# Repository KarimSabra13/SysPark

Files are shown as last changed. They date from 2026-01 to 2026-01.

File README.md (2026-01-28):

# SysPark – Smart Parking System (Documentation Repository)

SysPark is a smart parking demonstrator built as a distributed embedded system.  
This repository is a **documentation-first** deliverable: it contains architecture, flows, integration procedures, and reference documents. Source code can be added later without changing the documentation structure.

## 1) What SysPark does

SysPark automates entry and exit flows using multiple identification and control layers:

- **Entry lane**
  - Identify a user or a vehicle (RFID and optionally license plate)
  - Trigger actuation (barrier and/or elevator mechanism in the demonstrator)
  - Create a parking session

- **Exit lane**
  - Identify the vehicle/session
  - Validate payment (cloud-driven)
  - Unlock the exit sequence
  - Close the session

SysPark is designed to remain safe and usable even when:
- the cloud is unavailable,
- vision is unavailable,
- network connectivity is degraded.

## 2) System blocks (high-level)

SysPark is split into independent blocks that communicate mainly through MQTT.

### Edge Gateway (BeagleY-AI / BeagleBone AI class)
- Local MQTT broker (system bus on the parking LAN)
- Bridge between local LAN and the cloud
- Orchestration logic (system flows, supervision)
- Remote maintenance entry point (VPN overlay recommended)
- Optional hosting of AI/Vision inference

### FPGA Execution Node (Nexys A7-100T + LiteX RISC-V + Linux)
- Deterministic actuator control via CSR (memory-mapped control registers)
- Receives commands from MQTT and publishes barrier states
- Runs Linux to host integration services while keeping a simple control plane
- Uses a structured boot chain (LiteX BIOS → OpenSBI → Linux kernel + DTB + initramfs)

### STM32 Field Nodes (STM32F746G-DISCO + Zephyr RTOS)
- Ethernet-connected nodes close to lane equipment
- Real-time threading model (RFID acquisition, UI updates, storage, motion control)
- microSD persistence for local autonomy (PINs, ACL whitelist, minimal logs)
- Entry vs Exit roles supported depending on the lane

### AI / Vision (optional)
- License plate recognition pipeline at the edge
- Confidence-aware publishing to MQTT
- Never blocks the lane: always has fallback identifiers

### Power and Hardware
- Battery pack + BMS for protection and balancing
- DC-DC conversion (12 V class rail to stable 5 V distribution)
- Wiring topology designed for demo robustness (noise isolation, labeling, safety)

## 3) Repository structure

This repo is organized as a documentation system.

- `README.md`  
  Global overview (this file)

- `README.fr.md`  
  French version of the global overview

- `docs/en/`  
  English documentation by subsystem

- `docs/fr/`  
  French documentation by subsystem (mirrors `docs/en/`)

- `references/pdf/`  
  Reference PDFs used for the project (presentation, BMS, datasheets)

- `assets/`  
  Images, diagrams, exports (architecture visuals, screenshots, figures)

- `CHANGELOG.md`  
  Documentation evolution history

- `LICENSE`  
  Repository license

### Documentation sections
Inside `docs/*/` you will find:
- `overview/` : architecture, requirements, system flows, security, testing, deployment
- `edge/` : gateway role, MQTT bridge, remote access, LED banner integration
- `fpga/` : RISC-V on FPGA, boot chain, CSR control, networking
- `stm32/` : node overview, RTOS threads, Ethernet, storage microSD
- `cloud/` : cloud overview, payments, MQTT topic taxonomy
- `ai-vision/` : pipeline, streaming, models, validation
- `hw/` : high-level BOM, power and BMS, wiring topology

## 6) Getting started (documentation navigation)

Start here:
- `docs/en/overview/architecture.md`
- `docs/en/overview/system-flows.md`
- `docs/en/overview/deployment.md`
- `docs/en/overview/testing.md`

Then read per subsystem:
- `docs/en/edge/beagley-ai.md`
- `docs/en/fpga/riscv-overview.md`
- `docs/en/stm32/stm32-overview.md`
- `docs/en/hw/power-bms.md`

French equivalents are mirrored under `docs/fr/`.

## 7) Reference documents

- Presentation: `references/pdf/SysPark_Présentation.pdf`
- Power and BMS reference: `references/pdf/BMS.pdf`

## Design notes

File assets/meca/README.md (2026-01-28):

# SysPark - Documentation Mécanique (Impression 3D)

Ce répertoire contient l'ensemble des fichiers de conception mécanique nécessaires à l'assemblage physique du système de parking **SysPark**.  
Toutes les pièces ont été conçues pour être fabriquées via **impression 3D (FDM)**.

## 📂 Contenu du dossier

Le projet est divisé en quatre sous-ensembles principaux.

### 1. Support principal (STM32 + RFID + LCD)

**Dossier**  
`Support stm+rfid+lcd`

**Description**  
Châssis central du nœud de contrôle. Il permet de fixer solidement la carte **STM32F746G-DISCO**, le lecteur de badges **RFID RC522** et l'écran LCD intégré.

**Usage**  
Unité d'interface utilisateur à l'entrée et à la sortie du parking.

### 2. Support Écran OLED (Ascenseur)

**Dossier**  
`Ecran OLED ascenseur`

**Description**  
Boîtier compact conçu pour accueillir l'écran OLED déporté **SSD1306**.

**Usage**  
Fixation sur la structure de l'ascenseur afin d'indiquer l'étage ou le statut du véhicule.

### 3. Supports Caméras

Le système utilise deux types de supports selon la technologie de vision employée.

**Caméra CSI**  
Support optimisé pour les caméras à nappe de type **Raspberry Pi** ou **BeagleY-AI**, idéal pour la reconnaissance de plaques en pose fixe.

**Caméra Logitech**  
Support universel adapté aux webcams USB **Logitech** (C170, C920) pour une surveillance grand angle.

## 🛠 Paramètres d'Impression Recommandés

Afin de garantir la solidité mécanique et la précision des emboîtements, notamment pour les connecteurs USB de la STM32, les paramètres suivants sont recommandés.

**Matériau**  
PLA ou PETG. Le PETG est conseillé si le système est exposé à la chaleur.

**Hauteur de couche**  
0.2 mm.

**Remplissage (Infill)**  
15 % à 20 %, motif Gyroid ou Grille.

**Supports**  
Généralement non requis pour le support STM32. Ils peuvent être nécessaires pour certains supports caméras selon l'orientation d'impression.

**Brim / Bordure**  
Recommandé pour les pièces larges afin d'éviter le warping et le décollement des coins.

## 🔧 Instructions d'Assemblage

**Préparation**  
Nettoyer les restes de supports et vérifier l'ébavurage des trous de fixation.

**Montage électronique**  
La carte STM32 se fixe sur ses plots à l'aide de vis M3 de 6 mm à 10 mm.  
Le lecteur RFID se glisse ou se visse dans son logement dédié en vérifiant l'alignement de l'antenne.

**Fixation caméra**  
Les supports caméras sont conçus pour être orientables. Les vis de pivot doivent être serrées une fois l'angle de vue optimal obtenu.

**Intégration OLED**  
L'écran OLED doit être inséré délicatement afin d'éviter toute casse de la dalle en verre. Une fixation par clips ou un point de colle chaude est prévue selon la version du fichier.

## 📝 Format des fichiers

**STL**  
Fichiers directement importables dans les slicers tels que Cura, PrusaSlicer ou Bambu Studio.

**Note**  
Les fichiers sources CAD peuvent être ajoutés sur demande pour permettre la modification des tolérances ou des dimensions.

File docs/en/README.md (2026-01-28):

# SysPark Docs (EN)

## Overview
- Architecture: ../en/overview/architecture.md
- System flows: ../en/overview/system-flows.md
- Requirements: ../en/overview/requirements.md
- Security: ../en/overview/security.md
- Deployment: ../en/overview/deployment.md
- Testing: ../en/overview/testing.md

## Subsystems
- Cloud: ../en/cloud/cloud-overview.md
- Edge (BeagleY-AI): ../en/edge/beagley-ai.md
- STM32 (Zephyr): ../en/stm32/stm32-overview.md
- FPGA (RISC-V on LiteX): ../en/fpga/riscv-overview.md
- AI/Vision: ../en/ai-vision/pipeline.md
- HW/Power: ../en/hw/power-bms.md

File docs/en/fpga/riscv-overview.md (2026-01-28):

Language: English | [Français](../../fr/fpga/riscv-overview.md)

# RISC-V on FPGA Overview (LiteX + Soft SoC)

SysPark uses a RISC-V system running on an FPGA to implement a deterministic “execution node” that can safely drive actuators (barriers, motors) while still supporting a Linux environment for integration, tooling, and network services.

The idea is to combine:
- **hardware determinism** for control and I/O,
- **software flexibility** for messaging, logging, and system integration.

---

## 1) Why run RISC-V on an FPGA in SysPark

### Deterministic and low-level I/O
Actuation (barrier open/close, motor sequences) benefits from:
- predictable timing,
- direct memory-mapped register access,
- the ability to implement safety timeouts close to the hardware.

### Fast iteration for custom hardware interfaces
On an FPGA, SysPark can add or modify:
- PWM/stepper controllers,
- CSR-mapped GPIO blocks,
- additional sensors/encoders,
- watchdog and safety state machines,
without relying on a fixed off-the-shelf controller.

### Linux integration without losing control
Running Linux on the soft SoC enables:
- MQTT client services,
- secure payload handling,
- remote logging and maintenance,
- fast prototyping of on-device logic.

The FPGA remains the place where the “last mile” execution is controlled and made safe.

---

## 2) LiteX in one sentence

LiteX is used to generate a customizable SoC on the FPGA:
- a RISC-V CPU core,
- bus interconnect,
- memory controllers,
- and **CSR registers** that expose custom hardware blocks to software.

In SysPark, LiteX is the bridge between custom control logic in HDL and software services running on the CPU.

---

## 3) Soft SoC building blocks (SysPark view)

A typical SysPark FPGA SoC contains:

### CPU subsystem
- RISC-V soft core (e.g., VexRiscv class)
- on-chip ROM/BIOS stage (LiteX BIOS)
- DRAM controller (when using external DDR)

### Peripheral subsystem
- CSR-mapped GPIO blocks (for PMOD inputs/outputs)
- custom control IP (stepper driver output sequencing, PWM, etc.)
- UART for console
- Ethernet or MAC support if used for networking
- timers and interrupts used by Linux and by low-level services

### Memory and storage
- boot medium (SD or SPI flash depending on setup)
- runtime memory (DDR)

---

## 4) What CSR means in SysPark

CSR stands for Control and Status Registers:
- memory-mapped registers created by LiteX,
- accessible by software through simple reads/writes,
- used to control custom hardware blocks (set outputs, read inputs, trigger actions).

In SysPark, CSR registers provide the “actuator interface”:
- barrier control outputs are written through CSR-mapped GPIO,
- sensor inputs are read through CSR-mapped GPIO,
- Linux services translate MQTT commands into CSR writes.

This architecture avoids complex driver stacks and keeps the control path simple and transparent.

---

## 5) Separation of concerns (why this architecture is clean)

SysPark intentionally separates:
- **Decision layer** (cloud policies, edge orchestration)
- **Execution layer** (FPGA + CSR control)
- **Field interaction layer** (STM32 nodes close to sensors/motors)

The FPGA node is focused on:
- deterministic execution,
- safety boundaries,
- reliable low-level I/O,
not on high-level business logic.

---

## 6) Typical responsibilities of the FPGA execution node

- Subscribe to the local MQTT bus (or receive commands via the edge gateway).
- Validate and translate commands into hardware actions.
- Drive barrier outputs (stepper or motor driver chain).
- Read sensor inputs and publish states.
- Enforce timeouts and safe states in case of faults or missing heartbeats.
- Provide a clear software interface to the rest of the system.

---

## 7) Why open RISC-V is a good match (project philosophy)

RISC-V fits SysPark’s approach because:
- open ISA, easy to explain and document,
- strong ecosystem for soft cores and FPGA SoCs,
- aligns with an engineering demo where transparency matters,
- simplifies educational and research-driven iteration.

In practice, the value is the ability to generate the exact SoC needed and expose precise hardware control surfaces.

---

## 8) Acceptance criteria for the FPGA node

A correct FPGA execution node integration provides:
- stable boot chain to Linux,
- predictable CSR access (no address mismatch),
- reliable actuator control under MQTT command load,
- correct sensor sampling and state publishing,
- safe recovery on faults and timeouts.

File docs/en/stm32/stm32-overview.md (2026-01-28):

Language: English | [Français](../../fr/stm32/stm32-overview.md)

# STM32 Subsystem Overview (STM32F746G-DISCO + Zephyr RTOS)

In SysPark, the STM32 subsystem is the **field node** deployed close to the physical lane equipment. It executes deterministic, safety-oriented tasks (motor control, limit switches, RFID, local UI) and synchronizes its state with the Edge gateway (BeagleY-AI) through **Ethernet + MQTT**.

SysPark separates responsibilities on purpose:
- **Edge gateway decides** (orchestrates flows, merges vision + policies, bridges cloud),
- **STM32 executes locally** (timing-sensitive control, reliable I/O handling, local UI),
- **Execution hardware remains safe by design** (watchdogs/timeouts handled where needed).

---

## 1) Role inside SysPark

### Real-time field control
The STM32 node runs the “close-to-hardware” logic:
- stepper motor control through a driver that supports STEP/DIR (and optional configuration interface),
- homing and motion safety using end-stop/limit switch feedback,
- RFID badge reading for local identification,
- local display updates for lane feedback,
- local persistence for critical parameters (PINs, whitelist).

### Network synchronization
The STM32 node publishes events and receives approved commands via MQTT over Ethernet:
- publishes identification and sensor/actuator states,
- subscribes to selected commands and authorizations (notably payment success in exit flow),
- remains usable even when cloud connectivity is degraded (LAN-first behavior).

---

## 2) Why Zephyr RTOS

Zephyr is used for three main reasons:

### Determinism
Field interactions need predictable latency:
- step timing and motor sequencing,
- limit switch handling,
- UI refresh without blocking critical tasks.

### Embedded networking maturity
Zephyr provides a structured networking stack (Ethernet + IPv4 + sockets + MQTT patterns) suitable for microcontrollers with explicit RAM/CPU trade-offs.

### Reproducibility
Zephyr encourages reproducible configuration and portability:
- consistent build/config model,
- hardware description decoupled from application logic,
- easy to align behavior between developer machines and integration setups.

---

## 3) Hardware platform choice: STM32F746G-DISCO

The STM32F746G-DISCO board was selected because it offers:
- a high-performance Cortex-M7 suitable for mixed I/O + networking workloads,
- an integrated ST-LINK for simple flashing/debug,
- convenient expansion headers for motor drivers, RFID readers, displays, and sensors,
- Ethernet connectivity supported by Zephyr (RMII PHY commonly used in this platform).

---

## 4) Interfaces and peripherals (SysPark configuration)

SysPark’s STM32 integration targets a clear set of peripherals:

### Motor and safety I/O
- Stepper motor driver interface (STEP/DIR) and configuration channel if needed
- Limit switch input used for homing and safety boundaries
- Clear “safe state” behavior when faults occur or commands are inconsistent

### Identification (RFID)
- RFID reader used to capture badge UID
- UIDs are normalized and forwarded to the system bus for authorization decisions

### Local user interfaces
- A character LCD (20×4) can present operational data (status, messages, contextual info)
- An OLED screen can be used to show elevator/motion status (floor, direction, homing progress)

### Storage (microSD)
A microSD card is used to persist key data across reboots:
- entry PIN and exit PIN (if those modes are enabled),
- whitelist of authorized badge UIDs,
- optional field logs (events and diagnostics) in a structured, low-write-rate pattern.

---

## 5) Networking model (Ethernet, static IP, and MQTT)

### Ethernet basics
- The STM32 is a LAN node and communicates directly with the Edge gateway.
- Static IPv4 addressing is used to keep integration simple and predictable during demos and testing.

### MQTT integration intent
The STM32 acts as an MQTT client:
- publishes local events (RFID, barrier/elevator state, limit switch state),
- consumes selected decisions coming from the orchestration layer.

A strict topic taxonomy must be shared with BeagleY-AI to prevent mismatches and to keep the bridge allowlist minimal.

---

## 6) Execution modes: entry vs exit roles

SysPark can assign the STM32 node a **lane role**:

### Entry role (with elevator/motion control)
- performs homing on startup,
- drives the elevator/motion sequence deterministically,
- publishes elevator state periodically for supervision and UI.

### Exit role (payment-gated exit)
- focuses on identification + UI + exit authorization,
- waits for a “payment validated” authorization event before allowing exit progression,
- keeps local safety rules independent from cloud availability.

---

## 7) Concurrency model (threads and synchronization)

The application is structured as cooperative modules running at different priorities:
- MQTT communications and routing
- RFID acquisition
- UI rendering (LCD and OLED)
- motion control (entry role only)
- payment UI routing (exit role)

Synchronization is implemented using:
- message queues for UID and payment events,
- a semaphore-like mechanism to unblock UI after payment confirmation,
- a lock to protect microSD access between concurrent activities.

The goal is to avoid blocking operations in time-critical paths and to keep networking/UI/logging isolated from motor timing.

---

## 8) Field logging and robustness principles

To remain reliable in a real site:
- logs are written in a controlled manner (buffered + periodic flush),
- critical buffers and file structures are kept stable in memory,
- stack sizing is treated as a first-class constraint (avoid runtime faults),
- network behavior is validated with isolated subnets to avoid lab/router conflicts.

A separate Ethernet test flow exists in SysPark work to validate:
- TCP reception behavior,
- UART display output,
- and safe storage to microSD (file rotation, periodic synchronization).

---

## 9) Optional audio exploration (project extension)

An audio module was explored to support voice prompts around the elevator system:
- first approach: external text-to-speech board controlled by the STM32,
- second approach: investigation of the on-board audio chain (SAI/I2S codec).

This module is considered optional and was primarily used to evaluate feasibility and integration cost under Zephyr constraints.

---

## 10) Integration expectations (what “good” looks like)

A correct STM32 subsystem integration should provide:
- predictable motion control and safe homing,
- reliable RFID UID reporting,
- consistent UI behavior aligned with lane states,
- stable Ethernet connectivity and MQTT publication/subscription,
- robust behavior in degraded modes (cloud unreachable, broker unreachable),
- traceable local persistence (PINs/whitelist) and minimal SD wear.

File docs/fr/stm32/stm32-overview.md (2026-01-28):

Language: Français | [English](../../en/stm32/stm32-overview.md)

# Vue d’ensemble du sous-système STM32 (STM32F746G-DISCO + Zephyr RTOS)

Dans SysPark, le sous-système STM32 est le **nœud terrain** au plus près des équipements physiques de voie. Il exécute les tâches déterministes et orientées sûreté (pilotage moteur, fins de course, RFID, interface locale) et synchronise son état avec la passerelle Edge (BeagleY-AI) via **Ethernet + MQTT**.

SysPark sépare volontairement les responsabilités :
- **la passerelle décide** (orchestration, vision, politiques, bridge cloud),
- **le STM32 exécute localement** (contrôle I/O, temps réel, UI),
- **les mécanismes sûreté restent locaux** (comportement fiable en défaut).

---

## 1) Rôle dans l’architecture SysPark

### Contrôle terrain temps réel
Le STM32 gère la logique “proche matériel” :
- pilotage d’un moteur pas-à-pas via une interface driver de type STEP/DIR (et configuration si besoin),
- homing et limites mécaniques via fin de course,
- lecture badge RFID pour identification locale,
- mise à jour d’un affichage local,
- persistance locale des paramètres critiques (PIN, whitelist).

### Synchronisation réseau
Le STM32 publie des événements et reçoit des commandes approuvées via MQTT sur Ethernet :
- publication UID RFID et états capteurs/actionneurs,
- réception de certaines décisions (dont la validation de paiement en mode sortie),
- fonctionnement local prioritaire même en mode cloud dégradé.

---

## 2) Pourquoi Zephyr RTOS

Trois raisons principales :

### Déterminisme
Les interactions terrain demandent une latence maîtrisée :
- cadence moteur et séquences,
- lecture fin de course,
- rafraîchissement UI sans bloquer le critique.

### Réseau embarqué mature
Zephyr propose une pile réseau structurée (Ethernet + IPv4 + patterns MQTT) adaptée à microcontrôleur avec compromis explicites RAM/CPU.

### Reproductibilité
Modèle de configuration et d’intégration cohérent :
- configuration homogène,
- description matériel découplée,
- intégration reproductible en dev et en démo.

---

## 3) Plateforme matérielle : STM32F746G-DISCO

Choisie car :
- Cortex-M7 performant pour combiner I/O + réseau,
- ST-LINK intégré (flash/debug),
- headers pratiques pour driver moteur, RFID, écrans, capteurs,
- Ethernet compatible avec Zephyr (PHY RMII couramment utilisé sur cette carte).

---

## 4) Interfaces et périphériques (configuration SysPark)

SysPark cible un ensemble clair de périphériques :

### Moteur et sûreté I/O
- interface driver moteur (STEP/DIR) + canal de configuration si nécessaire
- fin de course pour homing et limites sûreté
- comportement en état sûr en cas d’anomalie ou de commande incohérente

### Identification (RFID)
- lecteur RFID pour récupérer l’UID badge
- normalisation de l’UID et publication sur le bus système pour décision d’accès

### Interfaces locales
- LCD 20×4 pour messages opérationnels (statut, informations contextualisées)
- OLED pour suivi ascenseur/mouvement (étage, direction, homing)

### Stockage (microSD)
La microSD sert à persister des éléments clés :
- PIN entrée et PIN sortie (si ces modes sont activés),
- liste whitelist des badges autorisés,
- logs terrain optionnels, structurés, à faible fréquence d’écriture.

---

## 5) Modèle réseau (Ethernet, IP statique, MQTT)

### Ethernet
- Le STM32 est un nœud LAN et dialogue avec la passerelle.
- L’adressage IPv4 statique simplifie les intégrations et les démos.

### Intentions MQTT
Le STM32 agit comme client MQTT :
- publie les événements locaux (RFID, états barrière/ascenseur, fin de course),
- consomme certaines décisions issues de l’orchestration.

Une taxonomie de topics strictement partagée avec BeagleY-AI est nécessaire pour éviter les désalignements et garder l’allowlist du bridge minimale.

---

## 6) Modes d’exécution : rôle entrée vs rôle sortie

SysPark peut assigner un **rôle de voie** au STM32 :

### Rôle entrée (avec ascenseur/mouvement)
- homing au démarrage,
- séquences de mouvement déterministes,
- publication régulière de l’état ascenseur pour supervision et UI.

### Rôle sortie (sortie conditionnée au paiement)
- priorité à l’identification + UI + autorisation sortie,
- attente d’un événement “paiement validé” avant de progresser,
- sûreté locale indépendante de la disponibilité cloud.

---

## 7) Modèle de concurrence (threads et synchronisation)

L’application est organisée en modules à priorités distinctes :
- communication et routage MQTT
- acquisition RFID
- rendu UI (LCD et OLED)
- pilotage mouvement (uniquement rôle entrée)
- routage UI paiement (rôle sortie)

Synchronisation via :
- files de messages pour UID et événements paiement,
- mécanisme type sémaphore pour débloquer l’UI après confirmation paiement,
- verrou pour protéger l’accès microSD en concurrence.

Objectif :
- éviter le blocage dans les chemins critiques,
- isoler réseau/UI/logging du timing moteur.

---

## 8) Logs terrain et principes de robustesse

Pour rester fiable :
- écriture logs contrôlée (buffer + flush périodique),
- structures mémoire stables pour éviter comportements indésirables,
- dimensionnement des piles traité comme contrainte centrale,
- validation réseau sur sous-réseaux isolés pour éviter conflits routeur/lab.

Un flow Ethernet de test a été utilisé pour valider :
- réception réseau,
- affichage UART,
- stockage microSD robuste (rotation, sync périodique).

---

## 9) Extension audio (optionnelle)

Une piste audio a été explorée pour des prompts autour de l’ascenseur :
- solution externe text-to-speech pilotée par le STM32,
- étude de la chaîne audio intégrée (SAI/I2S codec).

Cette brique est optionnelle et a surtout servi à évaluer la faisabilité et le coût d’intégration sous Zephyr.

---

## 10) Attendus d’intégration (critères de bon fonctionnement)

Une intégration STM32 correcte doit fournir :
- homing et contrôle mouvement prévisibles et sûrs,
- reporting UID RFID fiable,
- UI cohérente avec les états de voie,
- connectivité Ethernet stable et échanges MQTT corrects,
- comportement robuste en modes dégradés (cloud/broker indisponibles),
- persistance traçable (PIN/whitelist) et usure SD minimisée.

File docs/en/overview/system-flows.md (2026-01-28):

Language: English | [Français](../../fr/overview/system-flows.md)

# SysPark System Flows

This document describes the end-to-end operational flows of SysPark, from power-up to normal entry/exit cycles, including vision-assisted decisions, payment, operator overrides, degraded modes, and emergency handling. The goal is to make every subsystem role explicit and to keep boundaries stable: **Edge decides**, **FPGA executes safely**, **STM32 handles local terrain interactions**.

---

## 0) System bring-up and readiness (power-on to operational state)

### Trigger
- Mains power applied or system starts from backup battery.

### Steps
1. **Power and safety checks**
   - 12 V bus stabilizes, DC/DC converters supply logic rails.
   - BMS validates safe conditions (cell voltages, current limits, temperature).
   - If BMS detects an unsafe condition, the system stays in a restricted state (no actuation).

2. **Network initialization**
   - Edge gateway, FPGA node, and STM32 node bring up Ethernet links.
   - Static or DHCP addressing is applied depending on site configuration.

3. **Local control-plane availability**
   - The **local MQTT broker** becomes available on the parking LAN.
   - The system transitions to “local-operational” mode even if internet is not yet available.

4. **Cloud connectivity (optional but preferred)**
   - The MQTT bridge starts forwarding a *whitelisted* subset of topics to the public broker.
   - The cloud server connects to the broker and re-enables remote supervision features (dashboard, payments, remote logs).

5. **Subsystem health reporting**
   - Each subsystem publishes a heartbeat/status (edge, FPGA, STM32, sensors).
   - Edge consolidates system readiness and sets the initial user-facing messages (display banner).

### Outputs
- System state transitions to **READY** when:
  - BMS is OK,
  - LAN communication is OK,
  - execution nodes report healthy state.

---

## 1) Entry flow (vehicle arrival → authentication → barrier open → logging)

### Trigger
- Vehicle presence detected at entry lane (loop sensor, IR sensor, or equivalent).

### Inputs
- Presence sensor event
- Optional: camera snapshot / LPR result
- Authentication: RFID badge and/or PIN (site-dependent)

### Steps
1. **Arrival detection**
   - Presence event is published.
   - Edge updates the local display: “Please identify” or “Welcome”.

2. **Authentication**
   - **RFID badge path** (typical):
     - STM32 reads the badge UID and publishes an identification event.
     - Edge evaluates access based on:
       - local cached whitelist (offline-capable), and/or
       - cloud-managed policy (online mode).
   - **PIN path** (optional):
     - User enters PIN on the local interface.
     - STM32 forwards the entered PIN result as an event for validation.

3. **Decision**
   - Edge decides whether entry is granted:
     - policy checks (authorized user, time windows, capacity),
     - anti-passback logic if enabled (prevent “double entry” without exit),
     - optional coupling with vision confidence (if using LPR as an extra factor).

4. **Execution command**
   - Edge sends a barrier open request to the execution layer.
   - The FPGA (or the actuator controller designated as the executor) performs:
     - deterministic drive sequence,
     - safety checks (timeouts, motion bounds),
     - safe-state behavior if anomalies occur.

5. **Barrier open confirmation**
   - Executor reports: opened / opening / error.
   - Edge updates display: “Proceed” / “Wait” / “Error, call operator”.

6. **State update and traceability**
   - Entry event is logged (local and/or cloud):
     - timestamp, method (RFID/PIN/vision-assisted),
     - user identifier (masked where needed),
     - barrier status and any alarms.
   - Occupancy counters are updated.

### Outputs
- Barrier opens when authorized.
- Occupancy increments and session begins (in cloud DB if online).

---

## 2) Exit flow with payment (vehicle arrival → fee calculation → payment → barrier open)

### Trigger
- Vehicle presence detected at exit lane.

### Inputs
- Presence sensor event
- Optional: License Plate Recognition (LPR) result
- Payment status from the cloud (Stripe or equivalent)
- Exit PIN (optional fallback), operator override (fallback)

### Steps
1. **Arrival detection**
   - Presence event is published.
   - Display prompts: “Processing exit…” or “Please wait”.

2. **Vehicle identification**
   - Preferred: LPR provides plate number (+ confidence + timestamp).
   - Fallbacks:
     - RFID badge at exit,
     - exit PIN,
     - operator-assisted exit (manual override).

3. **Fee computation**
   - Cloud server computes fee based on session duration, tariffs, and rules.
   - Cloud emits a payment request event (amount, session reference).

4. **Payment interaction**
   - User completes payment through the cloud front-end.
   - Payment confirmation is generated by the payment provider and validated by the cloud (webhook).
   - Cloud publishes a **payment success** event linked to the session.

5. **Exit authorization**
   - The exit STM32 node receives “payment success” and unlocks the exit step.
   - Edge requests barrier opening from the executor.

6. **Execution + confirmation**
   - Executor opens the barrier with safety enforcement.
   - System logs:
     - payment confirmation,
     - exit timestamp,
     - barrier state and any warnings.

7. **Occupancy update**
   - Occupancy decrements.
   - Session is closed (in cloud DB if online).

### Outputs
- Barrier opens only after valid authorization (payment success or explicit override).
- Session is closed and revenue recorded.

---

## 3) Vision-assisted flow (camera → plate detection → OCR → validation → decision support)

### Trigger
- Vehicle presence or periodic capture policy.

### Inputs
- Camera frames (local capture)
- Vision model outputs (plate region, confidence)
- OCR result
- Validation rules (country format, allowed characters)

### Steps
1. **Capture and preprocessing**
   - Edge acquires frames and prepares them for inference.
   - Optional cropping or stabilization can be applied.

2. **Plate detection**
   - Vision model detects candidate plate region(s).
   - Edge selects the best candidate based on confidence and geometry.

3. **OCR and normalization**
   - OCR extracts characters.
   - Edge normalizes the string (cleanup, spacing, casing).
   - Format validation is applied (e.g., expected pattern constraints).

4. **Publishing results**
   - Edge publishes:
     - recognized plate,
     - confidence,
     - optional snapshot reference.

5. **Decision integration**
   - Entry: plate can be used as a second factor, or to pre-fill session identity.
   - Exit: plate is used to find the active session and compute fees.

### Failure handling
- If confidence is low or validation fails:
  - do not block the lane unnecessarily,
  - fallback to RFID/PIN/operator paths,
  - keep an “unverified plate” record for later review if needed.

---

## 4) Operator supervision and manual override flow (dashboard → action → audit)

### Trigger
- Operator opens the dashboard or receives an alert.

### Inputs
- System telemetry (status, heartbeats, alarms)
- Live debug stream (maintenance mode)
- Operator commands (manual barrier open, reset, config updates)

### Steps
1. **Observation**
   - Operator sees occupancy, recent events, alarm list, system health.
   - Optional: view a camera debug stream (secured access).

2. **Manual command**
   - Operator issues a command (e.g., open barrier, stop elevator, clear fault).
   - Command is authorized and logged (who/when/why).

3. **Execution**
   - Edge forwards the override request to the executor.
   - Executor performs action with safety limits.

4. **Audit trail**
   - Cloud stores the override event:
     - operator identity (or admin account),
     - reason (optional),
     - result and timing.

### Outputs
- Safe manual recovery path without bypassing the safety layer.

---

## 5) Configuration and access list management (cloud policy → edge → STM32 persistence)

### Trigger
- Admin updates authorized users, PINs, tariffs, or operational parameters.

### Inputs
- Admin action in the web interface
- Configuration payload (ACL list updates, PIN change, policy toggles)

### Steps
1. **Cloud publishes the update**
   - Changes are published as configuration events.

2. **Edge enforces boundaries**
   - Edge forwards only allowed configuration families to local systems.
   - Sensitive updates can require stronger authentication rules.

3. **STM32 applies and persists**
   - STM32 updates local stored configuration (e.g., whitelist, PINs) on SD storage.
   - STM32 republishes a “sync OK” status so the cloud knows it is applied.

### Outputs
- Offline-capable access control (cached whitelist / PINs).
- Clear “who changed what and when” traceability.

---

## 6) Degraded modes (internet down, broker down, subsystem fault)

SysPark is designed to keep the parking usable under partial failures.

### A) Internet down (cloud unreachable)
- Local broker continues functioning.
- Edge keeps basic entry/exit working with cached policies.
- Payments may be disabled or replaced by:
  - RFID-only exit for trusted users,
  - exit PIN,
  - operator override,
  depending on site policy.

### B) Cloud reachable but local execution node fault
- If an executor reports fault:
  - edge blocks automatic commands,
  - displays a clear user message,
  - notifies operator,
  - allows only manual recovery actions if safe.

### C) Vision degraded
- Vision failures should not block the lane:
  - revert to RFID/PIN,
  - store diagnostic markers for later tuning.

### D) Local broker down
- System can switch to a direct control-plane fallback if defined:
  - edge can attempt direct communication to executors,
  - or system can enter restricted state until broker returns.
- Recommended: keep broker as a supervised service with auto-restart.

---

## 7) Safety and emergency flow (obstruction, timeouts, fire alert)

### Trigger examples
- Obstruction detected while barrier closing.
- Movement timeout or inconsistent state.
- Fire alert signal received through an independent channel.

### Core safety rules
1. **Stop and safe state first**
   - executor stops motion and transitions to a safe state if:
     - obstruction is detected,
     - motion exceeds time window,
     - state becomes inconsistent.

2. **Clear operator messaging**
   - display: “Obstacle detected, please clear area” or “Call operator”.

3. **Alarm propagation**
   - alarm events are published locally and (if possible) forwarded to cloud.
   - operator is notified.

4. **Emergency policy**
   - for fire alert: apply the site-defined emergency policy, typically:
     - stop non-essential motion,
     - enable free exit or open barriers if safe and required,
     - keep logging for after-action review.

### Outputs
- Safety always overrides convenience.
- Emergency handling remains operational even if the main IP network is compromised.

---

## 8) What is logged (traceability baseline)

For each session and critical event, SysPark targets a consistent trace set:

- timestamps (entry, exit, payment success),
- authentication method (RFID, PIN, vision-assisted, override),
- system states and executor outcomes,
- alarms and recovery actions,
- operator actions with audit trail (when applicable).

This makes the system reviewable, debuggable, and demonstrable in an engineering context.

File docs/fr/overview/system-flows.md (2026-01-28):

Language: Français | [English](../../en/overview/system-flows.md)

# Flows système SysPark

Ce document décrit les flows opérationnels de SysPark, depuis la mise sous tension jusqu’aux cycles entrée/sortie, en incluant l’aide par vision, le paiement, les overrides opérateur, les modes dégradés et la gestion d’urgence. Objectif : rendre les rôles explicites et garder des frontières stables : **la passerelle décide**, **le FPGA exécute en sûreté**, **la STM32 gère les interactions terrain**.

---

## 0) Mise en route et état “READY” (power-on → système opérationnel)

### Déclencheur
- Alimentation secteur appliquée ou démarrage via la batterie de secours.

### Étapes
1. **Énergie et sûreté**
   - Stabilisation du bus 12 V, activation des conversions DC/DC.
   - Validation BMS (tensions cellules, limites courant, températures).
   - En cas d’anomalie BMS : système en état restreint (pas d’actionneurs).

2. **Initialisation réseau**
   - La passerelle, le FPGA et la STM32 montent les liens Ethernet.
   - Adressage statique ou DHCP selon configuration site.

3. **Plan de contrôle local**
   - Le **broker MQTT local** est disponible sur le LAN du parking.
   - Le système peut fonctionner en mode local même sans Internet.

4. **Connexion cloud (optionnelle mais recommandée)**
   - Le pont MQTT relaye une liste *whitelistée* de topics vers le broker public.
   - Le serveur cloud se connecte et réactive supervision et paiements.

5. **Santé sous-systèmes**
   - Chaque bloc publie un heartbeat/statut (passerelle, FPGA, STM32, capteurs).
   - La passerelle consolide l’état global et initialise les messages d’affichage.

### Sorties
- Passage en **READY** quand :
  - BMS OK,
  - communication LAN OK,
  - nœuds d’exécution en état sain.

---

## 1) Flow Entrée (arrivée véhicule → authentification → ouverture barrière → traçabilité)

### Déclencheur
- Présence véhicule détectée à l’entrée (capteur boucle/IR/etc.).

### Entrées
- Événement capteur de présence
- Optionnel : snapshot caméra / lecture plaque
- Authentification : badge RFID et/ou PIN (selon site)

### Étapes
1. **Détection arrivée**
   - Publication de l’événement de présence.
   - Mise à jour affichage : “Veuillez vous identifier” / “Bienvenue”.

2. **Authentification**
   - **Chemin badge RFID** (typique) :
     - STM32 lit l’UID et publie un événement d’identification.
     - La passerelle évalue l’accès via :
       - une whitelist locale mise en cache (mode offline), et/ou
       - une politique gérée côté cloud (mode online).
   - **Chemin PIN** (optionnel) :
     - Saisie PIN sur l’interface locale.
     - STM32 publie le résultat pour validation.

3. **Décision**
   - La passerelle autorise ou refuse l’entrée selon :
     - droits utilisateur, plages horaires, capacité,
     - anti-passback si activé (éviter une double entrée sans sortie),
     - optionnel : utilisation de la confiance vision comme facteur complémentaire.

4. **Commande d’exécution**
   - La passerelle envoie la demande d’ouverture vers la couche d’exécution.
   - Le FPGA (ou l’exécuteur dédié) applique :
     - séquence déterministe,
     - checks sûreté (timeouts, limites),
     - état sûr si anomalie.

5. **Confirmation**
   - Retour d’état : ouvert / en cours / erreur.
   - Affichage : “Passez” / “Patientez” / “Erreur, contactez l’opérateur”.

6. **Mise à jour et traçabilité**
   - Journalisation locale et/ou cloud :
     - timestamp, méthode (RFID/PIN/vision),
     - identifiant (masqué si besoin),
     - état barrière et alarmes.
   - Mise à jour occupation.

### Sorties
- Ouverture barrière si autorisé.
- Occupation + session d’entrée créée (cloud si online).

---

## 2) Flow Sortie avec paiement (arrivée → calcul tarif → paiement → ouverture)

### Déclencheur
- Présence véhicule détectée à la sortie.

### Entrées
- Événement présence
- Optionnel : résultat lecture plaque (LPR)
- Statut paiement depuis le cloud (Stripe ou équivalent)
- PIN sortie (fallback), override opérateur (fallback)

### Étapes
1. **Détection arrivée**
   - Publication de présence.
   - Affichage : “Sortie en cours…” / “Veuillez patienter”.

2. **Identification véhicule**
   - Prioritaire : LPR fournit plaque (+ confiance + timestamp).
   - Fallbacks :
     - badge RFID sortie,
     - PIN sortie,
     - assistance opérateur (override).

3. **Calcul tarif**
   - Serveur cloud calcule selon durée, tarifs, règles.
   - Cloud publie une demande de paiement (montant, référence session).

4. **Paiement**
   - Paiement via interface cloud.
   - Confirmation validée côté cloud (webhook).
   - Publication d’un événement **paiement validé** lié à la session.

5. **Autorisation sortie**
   - STM32 sortie reçoit “paiement validé” et déverrouille l’étape sortie.
   - Passerelle demande ouverture barrière à l’exécuteur.

6. **Exécution + confirmation**
   - Exécuteur ouvre avec sûreté.
   - Journalisation :
     - preuve paiement,
     - timestamp sortie,
     - état barrière + warnings.

7. **Mise à jour occupation**
   - Occupation décrémentée.
   - Session clôturée (cloud si online).

### Sorties
- Ouverture uniquement après autorisation (paiement validé ou override explicite).
- Revenu et session enregistrés.

---

## 3) Flow Vision (caméra → détection plaque → OCR → validation → support décision)

### Déclencheur
- Présence véhicule ou politique de capture périodique.

### Entrées
- Frames caméra
- Sorties modèle vision (zone plaque, confiance)
- OCR
- Règles de validation (format, caractères autorisés)

### Étapes
1. **Capture + prétraitement**
   - Acquisition image, préparation pour inference.
   - Optionnel : crop/stabilisation.

2. **Détection plaque**
   - Détection des régions candidates.
   - Sélection meilleure hypothèse (confiance + géométrie).

3. **OCR + normalisation**
   - Extraction caractères.
   - Nettoyage (espaces, casse, caractères parasites).
   - Validation format.

4. **Publication**
   - Publication plaque reconnue, confiance, optionnel snapshot.

5. **Intégration décision**
   - Entrée : second facteur ou pré-identification.
   - Sortie : rattachement à la session active pour calcul tarif.

### Gestion échecs
- Si confiance faible ou validation KO :
  - ne pas bloquer la voie,
  - basculer RFID/PIN/opérateur,
  - stocker un marqueur “non vérifié” pour analyse.

---

## 4) Supervision et override opérateur (dashboard → action → audit)

### Déclencheur
- Opérateur consulte le dashboard ou reçoit une alerte.

### Entrées
- Télémétries (statuts, heartbeats, alarmes)
- Flux debug (maintenance)
- Commandes opérateur (ouvrir barrière, reset, config)

### Étapes
1. **Observation**
   - Occupation, événements récents, alarmes, état système.
   - Optionnel : flux vidéo debug via accès sécurisé.

2. **Commande manuelle**
   - Action demandée (ouvrir barrière, stop mouvement, clear fault).
   - Autorisation + journalisation (qui/quand/pourquoi).

3. **Exécution**
   - Passerelle relaie vers l’exécuteur.
   - Exécuteur applique limites sûreté.

4. **Audit**
   - Cloud conserve l’événement :
     - identité opérateur/admin,
     - motif,
     - résultat et timing.

### Sorties
- Récupération sûre sans contourner la couche de sûreté.

---

## 5) Configuration et gestion des accès (politique cloud → passerelle → persistance STM32)

### Déclencheur
- Admin met à jour whitelist, PIN, tarifs, paramètres.

### Entrées
- Action admin via interface web
- Payload de configuration (ACL, PIN, options)

### Étapes
1. **Publication cloud**
   - Diffusion événement configuration.

2. **Contrôle passerelle**
   - Filtrage des familles autorisées vers le LAN.
   - Possibilité de renforcer l’auth sur changements sensibles.

3. **Application + persistance STM32**
   - STM32 met à jour config locale (whitelist/PIN) sur stockage SD.
   - STM32 publie “sync OK” vers le cloud.

### Sorties
- Mode offline possible (accès via cache).
- Traçabilité claire des changements.

---

## 6) Modes dégradés (perte Internet, panne nœud, vision KO)

SysPark vise une continuité d’usage sous pannes partielles.

### A) Internet indisponible
- Broker local continue.
- Passerelle maintient les flows basiques via cache.
- Paiements possibles à désactiver ou remplacer par :
  - sortie RFID pour utilisateurs de confiance,
  - PIN sortie,
  - override opérateur,
  selon politique site.

### B) Panne exécuteur local
- Si exécuteur en fault :
  - blocage automatique commandes,
  - affichage clair,
  - notification opérateur,
  - récupération manuelle encadrée si sûre.

### C) Vision dégradée
- Ne doit pas bloquer :
  - retour RFID/PIN,
  - collecte de diagnostics.

### D) Broker local indisponible
- Fallback possible si défini :
  - lien direct passerelle → exécuteurs,
  - ou état restreint jusqu’au retour broker.
- Recommandé : supervision service + auto-restart.

---

## 7) Flow sûreté et urgence (obstacle, timeout, alerte incendie)

### Déclencheurs typiques
- Obstacle pendant fermeture.
- Timeout mouvement ou état incohérent.
- Signal incendie via canal indépendant.

### Règles sûreté
1. **Stop + état sûr**
   - arrêt mouvement et état sûr si :
     - obstacle,
     - dépassement fenêtre temporelle,
     - incohérence d’état.

2. **Message utilisateur clair**
   - affichage : “Obstacle détecté, veuillez dégager” / “Contactez opérateur”.

3. **Propagation alarme**
   - publication locale puis cloud si possible.
   - notification opérateur.

4. **Politique urgence**
   - incendie : appliquer la politique définie site, typiquement :
     - arrêt mouvements non essentiels,
     - sortie libre ou ouverture barrière si requis et sûr,
     - journalisation pour post-mortem.

### Sorties
- La sûreté prime toujours.
- L’urgence reste gérable même si le réseau IP principal est compromis.

---

## 8) Ce qui est journalisé (base traçabilité)

Pour chaque session et événement critique :

- timestamps (entrée, sortie, paiement),
- méthode d’auth (RFID, PIN, vision, override),
- états système et résultats exécuteur,
- alarmes et actions de récupération,
- actions opérateur avec audit (si applicable).

Objectif : système démontrable, analysable, et maintenable.

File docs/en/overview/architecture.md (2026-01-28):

Language: English | [Français](../../fr/overview/architecture.md)

# SysPark System Architecture

SysPark is a modular smart-parking system designed as a complete, deployable solution rather than a loose set of sensors. The architecture is intentionally distributed and organized into clear responsibility layers, all interconnected over Ethernet. This separation keeps business decisions flexible while ensuring that safety-critical physical actions remain deterministic and robust.

## 1. Architectural principle: split responsibilities, keep interfaces stable

SysPark is built around three complementary execution layers:

- **Decision + supervision layer (Edge Gateway)**  
  A BeagleY-AI-class node is the integration point for high-level logic, cloud connectivity, vision/analytics, remote supervision, and operator-facing services.

- **Real-time execution layer (FPGA SoC)**  
  A Nexys A7 class FPGA running a LiteX SoC provides deterministic actuation and safety enforcement (timeouts, watchdogs, safe states). It executes commands reliably; it does not decide complex business rules.

- **Field interface layer (MCU node)**  
  An STM32F746G-DISCO class microcontroller running an RTOS handles local interactions near the equipment: RFID identification, elevator/actuator sequencing, local displays, and sensor acquisition, with predictable timing and structured multitasking.

A fourth cross-cutting block supports all layers:

- **Power + continuity layer (12 V bus + DC/DC + battery + BMS)**  
  A centralized 12 V DC bus simplifies distribution and supports heterogeneous loads. A backup battery and BMS provide continuity-of-service and energy safety, enabling controlled “safe shutdown” behavior.

This design rule stays constant across the project:

- **Beagle decides (business logic).**
- **FPGA executes (deterministic actuation + safety).**
- **STM32 interfaces with the field (local I/O + RTOS tasks).**

## 2. System-level topology

### 2.1 Networking and interconnection

All modules are connected using Ethernet, which standardizes integration and reduces point-to-point wiring complexity. A typical lab integration uses static IPv4 addressing for predictability (example values used during integration can be adapted per site):

- FPGA node: `192.168.10.4/24`
- Edge gateway: `192.168.10.5/24`
- STM32 node: `192.168.10.7/24`

Ethernet is used for:

- exchanging commands and acknowledgements,
- streaming sensor/actuator status to the gateway,
- transporting MQTT messages between subsystems (local broker and/or bridge).

### 2.2 Power distribution and continuity

SysPark uses:

- **12 V as the main distribution rail** (power domain),
- **5 V as the logic rail** (derived from 12 V via DC/DC conversion),
- a **backup battery** sized for peak power and safe-mode autonomy,
- a **BMS** ensuring protection, monitoring, and cell balancing.

The objective is not to replace mains permanently, but to **keep the system controllable long enough to finish a cycle, unlock safely, and enter a safe state** when supply conditions degrade.

## 3. Communication backbone: MQTT hybrid architecture

SysPark uses MQTT as the “system bus” for events, commands, telemetry, and operator messages.

### 3.1 Why hybrid (local + cloud)

The project uses a hybrid approach to get the best of both worlds:

- **Local MQTT broker** (inside the parking LAN):  
  fast local reactions, works even if internet is unstable, isolates sensitive equipment control.

- **Public broker relay + cloud server**:  
  enables remote supervision, centralized rule management, dashboards, payments and admin tools.

A **selective bridge** synchronizes only the required topics between local and cloud sides. A whitelist-based forwarding policy prevents loops and keeps the exposed surface minimal.

### 3.2 Topic taxonomy (conceptual)

Topics are structured hierarchically under a root (example: `parking/…`) to keep the system extensible. Typical families:

- `parking/sensor_*` for presence, gate sensors, health/heartbeat, errors
- `parking/gate/*` for barrier state, limit switches, commands
- `parking/display/*` for user-facing messages (LED banner, local UI)
- `parking/camera/*` for camera positioning commands and vision outputs
- `parking/config/*` for controlled configuration updates
- `parking/meteo` for contextual data (optional)

Quality-of-service is chosen per criticality:

- QoS 0 for non-critical periodic telemetry,
- QoS 1 for “must arrive at least once” commands,
- QoS 2 for critical configuration or safety events when exactly-once semantics matters.

## 4. Edge Gateway (BeagleY-AI): decision, fusion, supervision

The gateway is the system integration hub:

### 4.1 Decision engine and orchestration

It aggregates:

- field events (RFID, sensors, actuator status),
- vision outputs (plate recognition / confidence / snapshots),
- cloud-side decisions or policies (rules, capacity, operator overrides).

It then orchestrates:

- user guidance (display messages),
- barrier/elevator sequencing requests toward execution nodes,
- notifications and logging.

### 4.2 Local user information and remote supervision

Two key operator-facing functions are emphasized:

- **Local display**: a LED banner driven locally provides immediate feedback (“available spots”, “welcome”, “full”, “please wait”, etc.). The display subscribes to MQTT to update in real time.

- **Remote supervision**: a secure remote access tunnel enables operators/engineers to view a debug video stream without opening inbound ports on the site router. This supports maintenance and reduces deployment friction.

## 5. Field controller (STM32 + RTOS): deterministic terrain interactions

The STM32 subsystem is the “near-machine” node. It concentrates the physical I/O close to the barrier/equipment, and it uses RTOS multitasking to keep behavior predictable and maintainable.

### 5.1 Main responsibilities

- **RFID access control**: read badges and inject identification events into the system flow.
- **Actuator control (elevator, motors, etc.)**: execute local motion profiles with acceleration/deceleration logic, including a boot-time calibration (homing).
- **Local interface**: small displays and immediate user feedback.
- **Sensor acquisition**: temperature/pressure and other safety signals.
- **State synchronization**: publish status and receive commands over the network (via MQTT over Ethernet).

### 5.2 Design intent

The STM32 does not own complex business rules. It provides:

- stable and deterministic field I/O,
- clean separation of tasks (acquisition / display / communication),
- robust behavior under timing constraints.

## 6. FPGA SoC (Nexys A7 + LiteX + RISC-V Linux): deterministic execution and safety

The FPGA block exists to guarantee:

- **deterministic actuation timing**, independent of OS jitter,
- **safety enforcement** via watchdogs/timeouts and safe states,
- **reliable command execution** with explicit control interfaces.

### 6.1 Conceptual structure

- A LiteX SoC provides a clean separation between:
  - hardware logic for strict real-time functions,
  - a lightweight supervisory software layer running on a RISC-V CPU (Linux) for coordination and networking.

- Control is exposed through stable memory-mapped registers (CSR-like control surface), enabling explicit “set/read” semantics for actuators and status signals.

### 6.2 Integration flows

The FPGA exchanges with the gateway via Ethernet:

- **receives commands** to execute (open/close, position, drive),
- **returns status continuously** (states, positions, alarms),
- **enforces safe behavior** on anomaly detection.

## 7. Safety and emergency handling

Safety is designed into SysPark at multiple layers:

- **Local mechanical safety**: presence detection around barriers and controlled motion sequencing reduce risks.
- **Execution safety (FPGA)**: watchdogs/timeouts enforce safe states if commands become inconsistent or stale.
- **Energy safety (BMS)**: cell protection and safe operating area enforcement reduce thermal/chemical risk.
- **Emergency channel independence**: a fire alert mechanism is designed to use an independent radio channel outside the main IP network, ensuring the emergency signal can still reach the system in critical conditions.

## 8. Energy subsystem: BMS, battery sizing, and DC/DC strategy

The energy design is driven by heterogeneous loads and transient peaks:

- The overall system power budget is around the order of a few tens of watts, with peaks driven by motors/servos.
- A 12 V / 6 Ah battery is sized to sustain peak power and provide more than enough time to transition the system into a safe mode.
- The BMS functions include:
  - per-cell voltage monitoring, current and temperature tracking,
  - protection against over/under-voltage and over-current (MOSFET isolation),
  - passive balancing,
  - SOC/SOH estimation for supervision.

A pragmatic path was followed: initial custom BMS exploration for learning and architecture validation, then a commercial integrated BMS for reliability and delivery constraints.

## 9. Modularity and evolution

SysPark is designed to scale:

- from small sites (tens of spots) to larger deployments,
- to multiple entries/exits,
- to higher security requirements (more cameras, stronger policies),
- to additional sensing and diagnostics.

Because responsibilities are separated and interfaces are stable (Ethernet + MQTT + explicit status/command boundaries), new features can be added without destabilizing the safety-critical execution core.

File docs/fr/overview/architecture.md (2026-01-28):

Language: Français | [English](../../en/overview/architecture.md)

# Architecture système SysPark

SysPark est un système de parking intelligent conçu comme une solution complète, modulaire et orientée déploiement, plutôt que comme un simple assemblage de capteurs. L’architecture est volontairement distribuée, organisée en couches de responsabilités bien séparées, toutes interconnectées via Ethernet. Cette séparation permet de faire évoluer la logique métier sans fragiliser l’exécution temps réel et la sûreté des actions physiques.

## 1. Principe d’architecture : séparer les rôles, stabiliser les interfaces

SysPark repose sur trois niveaux complémentaires :

- **Niveau décision + supervision (Passerelle Edge)**  
  Un nœud de type BeagleY-AI sert de point d’intégration pour la logique haut niveau, la connectivité cloud, la vision, la supervision à distance et les services opérateur.

- **Niveau exécution temps réel (SoC sur FPGA)**  
  Un FPGA de type Nexys A7 avec un SoC LiteX assure l’exécution déterministe des commandes terrain et l’application des mécanismes de sûreté (timeouts, watchdogs, états sûrs). Il exécute de manière fiable, mais ne porte pas la décision métier complexe.

- **Niveau interface terrain (Nœud microcontrôleur)**  
  Un STM32F746G-DISCO sous RTOS gère les interactions locales au plus près des équipements : lecture RFID, séquencement ascenseur/actionneurs, affichage local, acquisition capteurs, avec une structure multi-tâches robuste.

Un bloc transverse supporte l’ensemble :

- **Énergie + continuité (Bus 12 V + conversion DC/DC + batterie + BMS)**  
  Un bus 12 V DC central simplifie la distribution, alimente les charges hétérogènes, et une batterie avec BMS garantit la continuité de service et la sûreté énergétique, afin d’atteindre un état sûr en cas de dégradation d’alimentation.

Règle d’architecture constante :

- **La passerelle décide (logique métier).**
- **Le FPGA exécute (temps réel + sûreté).**
- **La STM32 interfâce le terrain (I/O locales + tâches RTOS).**

## 2. Topologie système

### 2.1 Interconnexion réseau

Tous les modules communiquent via Ethernet, ce qui standardise l’intégration et limite le câblage point à point. En environnement de test, des adresses IPv4 statiques sont souvent utilisées pour la reproductibilité (valeurs indicatives, adaptables par site) :

- FPGA : `192.168.10.4/24`
- Passerelle : `192.168.10.5/24`
- STM32 : `192.168.10.7/24`

Ethernet sert à :

- transporter commandes, états et événements,
- échanger les statuts actionneurs/sécurités vers la passerelle,
- véhiculer les messages MQTT entre sous-systèmes (broker local et pont éventuel).

### 2.2 Distribution d’énergie et continuité

SysPark structure la puissance autour de :

- **12 V : rail principal** (puissance),
- **5 V : rail logique** (dérivé du 12 V par conversion DC/DC),
- une **batterie de secours** dimensionnée pour les pics et une autonomie de mise en sécurité,
- un **BMS** pour protection, mesure, équilibrage et supervision.

L’objectif n’est pas de remplacer durablement le secteur, mais de **maintenir le contrôle suffisamment longtemps pour terminer un cycle, sécuriser les actionneurs, puis basculer en état sûr**.

## 3. Colonne vertébrale de communication : MQTT hybride

MQTT est utilisé comme “bus système” pour les événements, commandes, télémétries et messages opérateur.

### 3.1 Intérêt du mode hybride (local + cloud)

L’architecture combine :

- **Un broker MQTT local** (sur le LAN du parking) :  
  latence faible, fonctionnement autonome même si l’accès Internet est instable, et contrôle mieux isolé.

- **Un relais public + un serveur cloud** :  
  supervision à distance, règles centralisées, tableaux de bord, paiements et administration.

Un **pont sélectif** synchronise uniquement les topics nécessaires entre local et cloud. Une politique de type whitelist évite les boucles et limite la surface exposée.

### 3.2 Taxonomie des topics (vue conceptuelle)

Les topics sont hiérarchiques sous une racine (ex : `parking/…`) pour rester extensibles. Familles usuelles :

- `parking/sensor_*` : présence, heartbeat, erreurs
- `parking/gate/*` : état barrière, fins de course, commandes
- `parking/display/*` : messages usagers (bandeau LED, IHM)
- `parking/camera/*` : commandes de positionnement et sorties vision
- `parking/config/*` : configuration contrôlée
- `parking/meteo` : contexte (optionnel)

Le QoS est choisi selon criticité :

- QoS 0 : télémetries non critiques,
- QoS 1 : commandes “au moins une fois”,
- QoS 2 : événements/configurations critiques si besoin d’exactement-une-fois.

## 4. Passerelle Edge (BeagleY-AI) : décision, fusion, supervision

La passerelle est le point d’intégration du système :

### 4.1 Moteur de décision et orchestration

Elle fusionne :

- événements terrain (RFID, capteurs, états actionneurs),
- sorties vision (lecture plaque, confiance, captures),
- règles et décisions issues du cloud (politiques, overrides opérateur).

Elle orchestre ensuite :

- guidage usager (messages d’affichage),
- demandes de séquences (barrières/ascenseur) vers les nœuds d’exécution,
- notifications et traçabilité.

### 4.2 Information locale et supervision à distance

Deux fonctions opérateur sont clés :

- **Affichage local** : un bandeau LED piloté localement fournit un retour immédiat (“places disponibles”, “bienvenue”, “complet”, etc.). Il est mis à jour en temps réel via abonnement MQTT.

- **Supervision à distance** : un accès distant sécurisé permet d’ouvrir un flux vidéo de debug sans ouvrir de ports entrants sur la box du site. Cela facilite maintenance, debug et déploiement.

## 5. Contrôleur terrain (STM32 + RTOS) : exécution locale et I/O déterministes

La STM32 est le nœud “au plus près” des équipements. Elle regroupe les entrées/sorties terrain et s’appuie sur une architecture RTOS multi-tâches pour garantir un comportement prévisible et maintenable.

### 5.1 Responsabilités principales

- **Contrôle d’accès RFID** : lecture badges et émission d’événements d’identification.
- **Commande actionneurs (ascenseur, moteurs, etc.)** : profils de mouvement avec accélération/décélération, et calibration (homing) au démarrage.
- **Interface locale** : affichages et retours utilisateur immédiats.
- **Acquisition capteurs** : température/pression et signaux de sûreté.
- **Synchronisation réseau** : publication d’états et réception de commandes via Ethernet/MQTT.

### 5.2 Intention de conception

La STM32 ne porte pas la logique métier complexe. Elle fournit :

- un socle terrain déterministe,
- un découpage clair des tâches (acquisition / affichage / communication),
- une robustesse temporelle adaptée aux contraintes réelles.

## 6. SoC FPGA (Nexys A7 + LiteX + RISC-V Linux) : déterminisme et sûreté d’exécution

Le FPGA garantit :

- **des temps d’exécution maîtrisés**, indépendants de la gigue OS,
- **des mécanismes de sûreté** (watchdogs, timeouts, états sûrs),
- **une exécution fiable** des commandes reçues.

### 6.1 Organisation conceptuelle

- Le SoC LiteX sépare :
  - la logique matérielle (fonctions strictement temps réel),
  - une couche de supervision légère (CPU RISC-V sous Linux) utile pour coordination et réseau.

- Le contrôle est exposé via une interface stable de type registres mémoire-mappés, offrant des commandes explicites et des retours d’état clairs.

### 6.2 Flux d’intégration

Le FPGA échange avec la passerelle via Ethernet :

- **réception de commandes** à exécuter,
- **retour continu d’état** (statuts, positions, alarmes),
- **passage en état sûr** lors de détection d’anomalies.

## 7. Sûreté et gestion d’urgence

La sûreté est traitée à plusieurs niveaux :

- **Sécurité locale** : capteurs de présence autour des barrières et séquences de mouvement contrôlées.
- **Sûreté d’exécution (FPGA)** : watchdogs/timeouts et états sûrs en cas d’incohérence.
- **Sûreté énergétique (BMS)** : protection cellules et respect de la zone de fonctionnement sûre.
- **Indépendance du canal d’urgence** : un mécanisme d’alerte incendie est pensé via un canal radio indépendant du réseau IP principal, afin de garantir la réception de l’alerte même en cas de panne réseau.

## 8. Énergie : BMS, dimensionnement batterie, conversion DC/DC

La conception énergie est dictée par des charges hétérogènes et des pics transitoires :

- un budget global de puissance de l’ordre de quelques dizaines de watts, avec des pics liés aux moteurs/servos,
- une batterie 12 V / 6 Ah dimensionnée pour tenir les pics et laisser le temps d’atteindre un état sûr,
- un BMS assurant :
  - mesure tension cellule, courant et température,
  - protection surcharge/sous-tension/surintensité (isolation par MOSFETs),
  - équilibrage passif,
  - estimation SOC/SOH exploitable en supervision.

La démarche a été pragmatique : exploration d’un BMS custom pour valider l’architecture, puis choix d’une solution commerciale intégrée pour sécuriser fiabilité et planning.

## 9. Modularité et évolutions

SysPark est conçu pour évoluer :

- du petit parking au multi-sites,
- en multipliant entrées/sorties,
- en renforçant sécurité et vision,
- en ajoutant capteurs, diagnostics et outils maintenance.

Grâce à la séparation des rôles et à des interfaces stables (Ethernet + MQTT + frontières commande/état), les nouvelles fonctionnalités peuvent être ajoutées sans déstabiliser le cœur d’exécution temps réel.

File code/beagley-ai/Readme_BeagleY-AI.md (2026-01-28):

# SysPark : Guide d'Implémentation du Nœud BeagleY-AI

## 1. Le Cœur Matériel : Analyse de la BeagleY-AI

Le choix de la plateforme matérielle est déterminant pour la viabilité d'une solution Edge AI. La **BeagleY-AI** a été sélectionnée pour SysPark en raison de son architecture hétérogène unique, offrant un équilibre optimal entre puissance de calcul généraliste et accélération matérielle spécialisée.

### 1.1 Spécifications Techniques et Pertinence pour SysPark

La BeagleY-AI repose sur le System-on-Chip (SoC) **Texas Instruments AM67A** (J722S), une puce conçue spécifiquement pour la vision industrielle et l'IA embarquée.<sup>12</sup>

| **Composant** | **Spécification** | **Rôle dans SysPark** |
|---|---|---|
| **CPU Application** | Quad-core Cortex-A53 @ 1.4 GHz (64-bit) | Exécution de l'OS Linux (Debian/TI Edge AI), du runtime Python, du broker MQTT et du serveur Web Flask. C'est le chef d'orchestre généraliste. |
| **Accélérateur IA (DSP)** | C7x DSP + MMA (Matrix Multiply Accelerator) | Capable de délivrer jusqu'à 4 TOPS (Trillions d'Opérations par Seconde). Il est dédié à l'inférence des réseaux de neurones profonds (YOLO) pour la détection de véhicules et de plaques, déchargeant le CPU principal. |
| **Processeur de Vision (ISP)** | VPAC (Vision Processing Accelerator) | Unité critique pour le pipeline vidéo. Elle traite le flux brut (RAW Bayer) des caméras, gère la balance des blancs, l'exposition automatique (AE) et la conversion de format (Demosaicing), sans latence CPU. |
| **Microcontrôleurs TR** | Cortex-R5F (x2) | Coeurs temps réel dédiés. Bien que SysPark utilise un STM32 externe, ces cœurs gèrent en interne la gestion de l'énergie et certains périphériques bas niveau du SoC. |
| **Mémoire** | 4 Go LPDDR4 | Suffisant pour stocker les modèles d'IA, les buffers vidéo GStreamer et l'OS complet. |
| **Connectivité** | Wi-Fi 6, Bluetooth 5.4, Gigabit Ethernet | Assure la liaison vers le Cloud (via Wi-Fi/Ethernet) et potentiellement vers des capteurs BLE futurs. |

Contrairement à une Raspberry Pi 4 ou 5 qui dépend fortement de son GPU VideoCore et de son CPU pour le traitement d'image, l'AM67A dispose de pipelines matériels dédiés (VPAC + DMPAC) qui permettent un traitement d'image déterministe et une consommation énergétique maîtrisée, crucial pour un boîtier de parking pouvant être exposé à la chaleur.

### 1.2 Topologie des Entrées/Sorties (Pinout) et Câblage

L'intégration physique de la BeagleY-AI dans le boîtier SysPark nécessite une compréhension précise du connecteur d'extension 40 broches. Bien que compatible physiquement avec le standard HAT Raspberry Pi, le multiplexage des broches (PinMux) sur le SoC TI AM67A est spécifique et nécessite une configuration logicielle précise via les "Device Tree Overlays".<sup>34</sup>

**Avertissement Critique** : Les niveaux logiques des GPIOs de la BeagleY-AI sont strictement en **3.3V**. Toute connexion directe avec des périphériques 5V (fréquents dans l'industrie ou sur Arduino/STM32 anciens modèles) sans adaptation de niveau (Level Shifter) entraînera la destruction immédiate du port GPIO, voire du SoC complet.<sup>5</sup>

#### 1.2.1 Le Bus SPI (Affichage LED Matriciel)

L'affichage des messages ("LIBRE", "COMPLET", Météo) est assuré par une chaîne de matrices LED pilotées par le contrôleur MAX7219. Ce composant utilise une interface série synchrone SPI (Serial Peripheral Interface). Sur la BeagleY-AI, nous exploitons le bus **SPI0** mappé pour correspondre au standard Raspberry Pi.<sup>6</sup>

-   **MOSI (Master Out Slave In) - Pin 19 (GPIO 10)** : C'est la ligne de données principale. La BeagleY-AI (Maître) envoie les commandes d'allumage des pixels aux modules LED (Esclaves). Le script bandeau_led.py écrit des trames binaires sur cette ligne.<sup>1</sup>

-   **SCLK (Serial Clock) - Pin 23 (GPIO 11)** : L'horloge de synchronisation. Générée par la BeagleY-AI, elle cadence la lecture des bits par le MAX7219. La fréquence est configurée à 1 MHz dans le script.

-   **CE0 (Chip Select 0) - Pin 24 (GPIO 8)** : Ligne de sélection de l'esclave. Lorsqu'elle est passée à l'état bas (Low), le MAX7219 écoute le bus. C'est essentiel pour initier une transaction SPI valide.

-   **MISO (Master In Slave Out) - Pin 21 (GPIO 9)** : Bien que présente physiquement, cette ligne n'est pas câblée aux matrices LED MAX7219 car la communication est unidirectionnelle (la BeagleY-AI envoie des données, mais les matrices ne répondent pas).

Pour que ces broches fonctionnent en mode SPI et non en GPIO simple, l'overlay k3-am67a-beagley-ai-spidev0.dtbo doit être chargé au démarrage.<sup>7</sup> Cela expose le périphérique /dev/spidev0.0 au niveau du noyau Linux.

#### 1.2.2 Interface GPIO (Capteur de Présence & Barrière)

La détection de véhicule à la barrière (simulation de boucle d'induction ou cellule photoélectrique) est gérée par une entrée numérique simple.

-   **Signal - Pin 11 (GPIO 17)** : Cette broche est configurée en entrée (Input). Le script sensor_gate.py <sup>1</sup> surveille l'état de cette ligne.

    -   *État Haut (3.3V)* : Véhicule présent (ou absence de faisceau, selon la logique du capteur - NC/NO).

    -   *État Bas (0V)* : Voie libre.

-   **Masse (GND) - Pin 9, 25, 39, etc.** : Référence commune obligatoire entre le capteur et la BeagleY-AI.

La documentation <sup>8</sup> confirme que la Pin 11 correspond bien au GPIO 17 du SoC (Net name : GPIO1_8 ou SoC Pin A26 selon le multiplexage, mais mappée logiciellement comme GPIO 17 pour compatibilité RPi).

#### 1.2.3 Interface Caméra (MIPI CSI-2)

La capture vidéo haute performance ne passe pas par l'USB (trop de latence et charge CPU), mais par l'interface **CSI (Camera Serial Interface)**.

-   **Connecteur** : La BeagleY-AI dispose de connecteurs 22-pin FPC (Flexible Printed Circuit).

-   **Modèle** : Caméra IMX219 (Sony Exmor R), standard de facto pour les projets embarqués.

-   **Topologie** : La caméra est connectée en point-à-point différentiel haut débit. Cela nécessite l'activation de l'overlay k3-am67a-beagley-ai-csi0-imx219.dtbo.<sup>2</sup> Cet overlay configure le PHY D-PHY du SoC pour recevoir les signaux LVDS de la caméra et router le flux vers le VPAC.

## 2. Stratégie Système : OS, Installation et Drivers

Le socle logiciel est le fondement de la stabilité de SysPark. Pour la BeagleY-AI, deux philosophies s'affrontent : l'image Debian générique maintenue par la fondation BeagleBoard, et l'image SDK (Software Development Kit) optimisée par Texas Instruments pour l'Edge AI.

### 2.1 Analyse Comparative des Images Système

Les recherches <sup>91011</sup> mettent en évidence une dichotomie critique :

1.  **Image BeagleBoard Debian (XFCE/Minimal)** :

    -   *Avantages* : Très proche d'une expérience Debian standard, mises à jour via apt, large support communautaire.

    -   *Inconvénients majeurs pour SysPark* : Le support de l'accélération matérielle (C7x DSP, VPAC ISP) et des plugins GStreamer associés (tiovxisp) est souvent expérimental, absent, ou nécessite une recompilation complexe du noyau et des modules.<sup>2</sup>

    -   *Risque* : Sans accélération, le traitement vidéo 1080p se ferait entièrement sur le CPU, saturant les cœurs A53 et rendant le système instable.

2.  **Image TI Edge AI (Basée sur Yocto/Arago)** :

    -   *Avantages* : Contient "out-of-the-box" tous les drivers propriétaires TI, les firmwares pour le DSP et le R5F, et surtout les plugins GStreamer tiovx optimisés. C'est l'image recommandée pour toute application de vision.<sup>12</sup>

    -   *Inconvénients* : Système de fichiers parfois en lecture seule (overlayFS), gestionnaire de paquets moins flexible (parfois opkg au lieu de apt, bien que les versions récentes intègrent apt), environnement plus "figé".

**Décision Architecturale** : Pour les déploiements SysPark, nous distribuons une **image disque SysPark prête à l'emploi** (basée sur TI Edge AI et déjà préconfigurée pour le projet). Cela garantit la disponibilité immédiate des drivers et accélérateurs (VPAC/tiovxisp, etc.) nécessaires au pipeline de vision, tout en figeant un socle stable pour l'intégration terrain.

### 2.2 Procédure d'installation et de mise en route (image SysPark prête à l'emploi)

Le nœud BeagleY-AI destiné à SysPark ne se déploie **pas** en réinstallant manuellement une distribution TI/Debian ni en reconstruisant l'environnement Python. Le système (serveur local, affichage LED, caméras, services, configuration de base) est livré sous forme **d'image disque** déjà préparée.

#### Phase 1 : Pré-requis

1. Une carte BeagleY-AI.
2. Une carte microSD de 16 Go minimum (32 Go recommandé).
3. Un ordinateur (Windows, macOS ou Linux) avec un lecteur microSD.
4. Un outil de flashage (balenaEtcher recommandé).

#### Phase 2 : Flashage de l'image SysPark sur microSD

1. Télécharger et installer balenaEtcher : [https://etcher.balena.io/](https://etcher.balena.io/)
2. Récupérer l'image disque SysPark (fichier `.img`) fournie pour le projet. [https://drive.google.com/file/d/1gn_GpR_V2WfZ9HwwYjGpSotGyj_53xE5/view?usp=sharing](https://drive.google.com/file/d/1gn_GpR_V2WfZ9HwwYjGpSotGyj_53xE5/view?usp=sharing)
3. Flasher la carte microSD avec balenaEtcher (sélection de l'image, sélection de la carte cible, écriture).
4. À la fin du flashage, certains systèmes (notamment Windows) peuvent proposer de formater la carte : il faut **refuser**. La carte contient des partitions Linux valides, simplement non reconnues par Windows.

#### Phase 3 : Premier démarrage

1. Éjecter proprement la microSD puis l'insérer dans la BeagleY-AI.
2. Brancher l'alimentation USB-C.
3. Connecter l'Ethernet (recommandé au premier démarrage).

Au premier boot, l'image peut effectuer une adaptation automatique à la taille de la microSD (extension de partition) et redémarrer. Laisser le nœud démarrer complètement (en pratique 1 à 2 minutes) afin que l'ensemble des services (serveur, affichage, vision, MQTT) se lance.

#### Phase 4 : Accès SSH (Ethernet préconfiguré)

Dans l'image SysPark, l'interface Ethernet est déjà configurée avec l'adresse statique suivante :

```bash
ssh root@192.160.10.1
```

Après connexion, sécuriser immédiatement le nœud (au minimum via la commande `passwd`). L'ajout d'un utilisateur non-root et l'authentification par clé SSH sont recommandés en exploitation, tout en gardant une procédure root disponible pour la maintenance.

#### Phase 5 : Accès au tableau de bord Web

Depuis un poste sur le même réseau, accéder au service Web local :

```text
http://192.160.10.1:5000
```

Selon l'environnement réseau (mDNS/Avahi), l'accès par nom peut aussi fonctionner :

```text
http://beagley-ai.local:5000
```

#### Phase 6 : Personnalisation obligatoire avant mise en service

L'image SysPark contient des réglages de démonstration et/ou de sauvegarde. Avant toute mise en service sur un nouveau site, il faut impérativement :

1. Changer la configuration Wi-Fi pour utiliser le réseau du site.
2. Remplacer toutes les clés / abonnements des services externes (HiveMQ Cloud, Tailscale, API météo, etc.) par les valeurs du client ou de l'exploitant.

Ces opérations sont détaillées en section 3.3.

#### Phase 7 : Comprendre le contenu de l’image SysPark (ce qui est déjà préinstallé)

L’image SysPark n’est pas seulement un système qui “démarre”, c’est un nœud BeagleY‑AI déjà câblé logiciellement pour exécuter la passerelle Edge du projet. Le dossier opérationnel est livré dans `/opt/edgeai-gst-apps` et les services correspondants sont déjà déclarés dans `/etc/systemd/system`.

##### 7.1 Matériel attendu et interfaces

Le fonctionnement nominal de l’image suppose la présence des éléments matériels suivants, car les scripts et services correspondants sont déjà prévus dans l’intégration.

Composant | Interface | Rôle
---|---|---
BeagleY‑AI | Carte SBC | Passerelle Edge, broker MQTT local, pont MQTT cloud, serveurs et logique locale
Caméra 1 IMX219 | CSI | Caméra principale pour la vision IA et la lecture de plaque
Caméra 2 USB | USB | Caméra secondaire, suivant l’intégration
Bandeau LED MAX7219 x4 | SPI (`/dev/spidev0.0`) | Affichage local des états et messages
Driver PCA9685 | I2C (`0x40`) | Génération PWM pour servos (Pan/Tilt)
Servomoteurs x4 | PWM | Orientation des deux caméras motorisées (Pan/Tilt)

##### 7.2 Arborescence livrée dans /opt/edgeai-gst-apps

Le projet est déployé directement dans `/opt/edgeai-gst-apps` et cette arborescence contient à la fois les scripts SysPark et des éléments “EdgeAI” issus de l’écosystème TI.

Référence de contenu observé dans l’image (extrait `ls`), utile pour se repérer lors d’un audit ou d’un dépannage.

```text
/opt/edgeai-gst-apps
Arducam-pivariety-v4l2-driver  (nom exact selon l’image)
CONTRIBUTING
LICENSE
README.md
[Unit]  (entrée anormale, peut être supprimée si inutile)
apps_cpp
apps_python
bandeau_led.py
beagle-ai.tail2fb2e4.ts.net.crt
beagle-ai.tail2fb2e4.ts.net.key
beagle_vision_combined.py
best.pt
cleaner.py
configs
docker
download_models.sh
download_test_data.sh
find_pins.py
force_all_neutra.sh
gate_zone_sensor.py
gnuradio
init_script.sh
optiflow
queue
scripts
sensor_gate.py
serveur
servo_calibration.py
servo_camera.py
setup_script.sh
simple_broker.py
start_vision.sh
test_simple_servo.py
tests
v4l2src
venv
```

Les éléments les plus importants, car directement liés au fonctionnement SysPark, sont les suivants.

Élément | Type | Rôle dans SysPark | Remarques d’exploitation
---|---|---|---
`beagle_vision_combined.py` | Script Python | Vision IA, détection, OCR, streaming MJPEG | Généralement lancé via `start_vision.sh`
`start_vision.sh` | Script shell | Point d’entrée vision | Active le venv et prépare `LD_LIBRARY_PATH` (plugins GStreamer)
`best.pt` | Modèle YOLO | Modèle de détection (plaques/véhicules) | À conserver avec le script vision
`simple_broker.py` | Script Python | Broker MQTT local (résilience) | Écoute typiquement en 1883
`mqtt_bridge.py` | Script Python | Pont MQTT local <-> cloud en TLS | Contient hôte, identifiants, CA, règles de filtrage
`bandeau_led.py` | Script Python | Pilotage bandeau LED (SPI) | Abonné à `parking/display/text`
`meteo_client.py` | Script Python | Client API météo et publication MQTT | Clé API et localisation à personnaliser
`sensor_gate.py` | Script Python | Lecture capteur présence barrière | Publie l’état sur MQTT
`servo_camera.py` | Script Python | Pilotage servos via PCA9685 (I2C) | Abonné à `parking/camera/cmd`
`venv/` | Dossier | Environnement Python isolé | Contient les dépendances déjà installées
`serveur/` | Dossier | Composants serveur local | Heberge le script mqtt_bridge.py et meteo_client.py
`beagle-ai.tail2fb2e4.ts.net.crt` et `.key` | Certificats | Artefacts liés à Tailscale | À régénérer après rattachement au compte Tailscale du client

L’arborescence contient aussi des outils et répertoires non spécifiques à SysPark, mais présents car l’image s’appuie sur l’écosystème TI EdgeAI, par exemple `apps_cpp`, `apps_python`, `optiflow`, `docker`, `tests`, ou des scripts utilitaires (`download_models.sh`, `download_test_data.sh`, etc.). Ils sont utiles pour diagnostiquer ou étendre, mais ne sont pas requis pour l’exploitation minimale.

##### 7.3 Services systemd déjà installés

Les scripts SysPark sont exécutés au démarrage via des unités systemd déjà présentes, notamment `simple_broker.service`, `mqtt_bridge.service`, `beagle_vision.service`, `bandeau_led.service`, ainsi que `meteo_client.service`, `sensor_gate.service` et `servo_camera.service`.

Référence de contenu observé dans l’image (extrait `ls`). Les unités `.service` ci-dessous portent le fonctionnement SysPark, le reste correspond au socle système et aux dépendances de démarrage.

```text
/etc/systemd/system
bandeau_led.service
beagle_vision.service
bluetooth.target.wants
ctrl-alt-del.target
dbus-org.bluez.service
dbus-org.freedesktop.Avahi.service
dbus-org.freedesktop.network1.service
dbus-org.freedesktop.resolve1.service
dbus-org.freedesktop.timesync1.service
dbus.service
default.target
display-manager.service
edgeai-init.service
getty.target.wants
local-fs.target.wants
meteo_client.service
mqtt_bridge.service
multi-user.target.wants
network-online.target.wants
sensor_gate.service
servo_camera.service
simple_broker.service
sockets.target.wants
sysinit.target.wants
systemd-hostnamed.service
systemd-journald.service.wants
systemd-random-seed.service.wants
systemd-udevd.service
timers.target.wants
```

Les sous-répertoires `*.target.wants` correspondent à des liens gérés par systemd pour l’activation automatique au boot.

Le point important est que les services sont le “contrat” d’exécution en production. Après modification d’identifiants (HiveMQ, Tailscale, météo) ou de paramètres matériels (caméra, SPI, I2C), il faut redémarrer le service concerné et vérifier ses logs via `journalctl`.

##### 7.4 Cartographie services <-> exécutables

Service systemd | Exécutable typique | Fonction
---|---|---
`simple_broker.service` | `simple_broker.py` | Broker MQTT local
`mqtt_bridge.service` | `mqtt_bridge.py` | Pont MQTT vers HiveMQ Cloud en TLS
`beagle_vision.service` | `start_vision.sh` puis `beagle_vision_combined.py` | Vision IA + streaming MJPEG
`bandeau_led.service` | `bandeau_led.py` | Bandeau LED SPI
`meteo_client.service` | `meteo_client.py` | Client météo, publication MQTT
`sensor_gate.service` | `sensor_gate.py` | Capteur présence, publication MQTT
`servo_camera.service` | `servo_camera.py` | Servos Pan/Tilt via I2C

##### 7.5 Accès au flux vidéo et maintenance à distance (Tailscale)

Le flux MJPEG issu du module vision est exposé classiquement sur le port 8000, avec une route de type `/mjpeg/cam1`. En local, cela permet de vérifier le cadrage et la mise au point sans outil spécifique.

```text
http://<IP_BEAGLE>:8000/mjpeg/cam1
```

Pour la télémaintenance, l’image peut s’appuyer sur Tailscale. Après rattachement au compte Tailscale du client, deux approches sont usuelles.

La première consiste à utiliser directement l’IP Tailscale (réseau 100.x) ou le nom MagicDNS de la machine pour atteindre le port 8000 à l’intérieur du réseau privé Tailscale.

La seconde consiste à activer un accès HTTPS public via Funnel sur ce port, ce qui renvoie une URL https unique.

```bash
sudo tailscale funnel 8000
```

Dans l’architecture SysPark, cette URL est ensuite reportée côté serveur cloud dans la variable historiquement nommée `NGROK_BASE` (même si le transport n’est pas ngrok) afin que les opérateurs puissent ouvrir le flux vidéo sans être sur le LAN du parking.

Après modification de l’accès distant, vérifier que les fichiers de certificat présents dans `/opt/edgeai-gst-apps` correspondent bien au domaine/compte Tailscale utilisé, puis régénérer si nécessaire.

### 2.3 Paramétrage initial après connexion (réseau, sécurité, abonnements)

Cette phase se fait directement en SSH (connexion root) après le premier démarrage.

#### 2.3.1 Sécurisation minimale

1. Changer le mot de passe root.

```bash
passwd
```

2. Configurer l'accès SSH par clés et, en production, limiter l'accès root (clé uniquement ou désactivation du login root), en s'appuyant sur un utilisateur d'exploitation dédié.

#### 2.3.2 Configuration Wi-Fi (remplacer le réseau par défaut)

La méthode exacte dépend du gestionnaire réseau présent dans l'image (NetworkManager, wpa_supplicant, systemd-networkd). La procédure ci-dessous est robuste : elle privilégie NetworkManager si disponible, sinon bascule sur une configuration wpa_supplicant.

Vérifier d'abord la présence de NetworkManager :

```bash
nmcli --version
```

Si `nmcli` est disponible, configurer le Wi-Fi via :

```bash
nmcli dev wifi list
nmcli dev wifi connect "<SSID>" password "<MOT_DE_PASSE>"
```

Si `nmcli` n'est pas présent, configurer via wpa_supplicant (cas fréquent sur images légères) :

1. Éditer `/etc/wpa_supplicant/wpa_supplicant.conf` et ajouter un bloc `network` pour le SSID du site.
2. Redémarrer le service réseau (ou redémarrer le nœud).

Après configuration, vérifier l'obtention d'une adresse IP et la connectivité :

```bash
ip a
ping -c 3 1.1.1.1
ping -c 3 google.com
```

#### 2.3.3 Remplacement des abonnements et clés API (HiveMQ, Tailscale, météo, etc.)

L'image SysPark inclut des identifiants de démonstration et/ou des valeurs liées à l'environnement de sauvegarde. Ils doivent être remplacés avant toute utilisation.

Recommandation : ne pas modifier en dur les scripts, mais centraliser les secrets dans un fichier de configuration (type `/opt/edgeai-gst-apps/.env` ou `/etc/syspark/secrets.env`) et/ou dans des overrides systemd (`Environment=`). Si l'image a été figée avec des valeurs en dur, l'approche ci-dessous permet de localiser rapidement les points à modifier.

1. Identifier où les paramètres sont stockés (configuration ou code) :

```bash
cd /opt/edgeai-gst-apps
grep -RIn "hivemq\|mqtt\|broker\|openweather\|weather\|tailscale\|authkey\|apikey" .
```

2. Paramétrer HiveMQ Cloud (MQTT distant) :

Mettre à jour l'hôte/port MQTT TLS, l'identifiant, le mot de passe, et le CA si nécessaire. Puis redémarrer le service de pont MQTT (script `mqtt_bridge.py` ou équivalent).

3. Paramétrer Tailscale :

Se déconnecter de l'ancienne identité, puis rattacher le nœud au compte du client avec une clé d'authentification générée dans l'admin console Tailscale :

```bash
tailscale logout
tailscale up --authkey "<TS_AUTHKEY>" --hostname "syspark-beagley-ai"
```

4. Paramétrer l'API météo :

Mettre à jour la clé OpenWeatherMap (ou service équivalent), ainsi que la localisation si elle est utilisée. Puis redémarrer le service météo (script `meteo_client.py` ou équivalent).

#### 3.3.4 Redémarrage des services et vérifications

Lister les services SysPark installés :

```bash
systemctl list-units --type=service | grep -i syspark
```

Vérifier l'état, puis redémarrer les services affectés :

```bash
systemctl status <service>
systemctl restart <service>
```

Contrôler les logs :

```bash
journalctl -u <service> -f
```

### 2.4 Environnement Python et Dépendances

Dans l'image SysPark prête à l'emploi, l'environnement d'exécution nécessaire est déjà installé et les services sont déjà configurés. Cette section reste utile pour comprendre la pile logicielle, dépanner, ou reconstruire une image propre à partir d'une base TI/Debian.

L'écosystème Python moderne (PEP 668) impose l'utilisation d'environnements virtuels pour éviter de corrompre le gestionnaire de paquets système (apt).

1.  **Installation des pré-requis système** :  
```bash
sudo apt update
sudo apt install -y python3-pip python3-venv \
libgpiod-dev gpiod \
tesseract-ocr tesseract-ocr-fra \
libopencv-dev python3-opencv \
gstreamer1.0-tools gstreamer1.0-plugins-base gstreamer1.0-plugins-good gstreamer1.0-plugins-bad \
libgstreamer1.0-dev libgstreamer-plugins-base1.0-dev
```

*Note* : libgpiod-dev est crucial pour le pilotage moderne des GPIOs. tesseract-ocr installe le moteur de reconnaissance optique de caractères.

2.  **Création de l'environnement virtuel (venv)** :  
```bash
# Création du dossier projet
sudo mkdir -p /opt/edgeai-gst-apps
sudo chown $USER:$USER /opt/edgeai-gst-apps
cd /opt/edgeai-gst-apps

# Création du venv
python3 -m venv venv

# Activation
source venv/bin/activate
```

3.  **Installation des librairies Python** : Les scripts fournis nécessitent un ensemble précis de bibliothèques <sup>11111</sup> :  
```bash
pip install paho-mqtt # Client MQTT (Broker & Bridge)
pip install requests # Appels HTTP (Meteo & Vision backend)
pip install flask # Serveur Web (Streaming MJPEG)
pip install numpy # Manipulation matrices image
pip install ultralytics # Framework YOLO (Vision)
pip install pytesseract # Wrapper OCR
pip install smbus2 # Bus I2C (si utilisé futur)
pip install amqtt # Broker MQTT asynchrone (pour simple_broker.py)
```

*Point d'attention* : Le script beagle_vision_combined.py <sup>1</sup> tente d'ajouter manuellement un chemin site-packages au sys.path (/opt/edgeai-gst-apps/venv/...). Cela indique qu'il a été conçu pour tourner dans l'environnement par défaut de l'image TI. Dans notre installation "propre", il faudra peut-être commenter ces lignes ou adapter le chemin vers notre /opt/edgeai-gst-apps/venv.

## 3. Infrastructure de Communication : Le Backbone MQTT

L'architecture SysPark repose sur le paradigme **Publish/Subscribe** via le protocole MQTT (Message Queuing Telemetry Transport). Ce choix est dicté par la nature distribuée du système, la nécessité de découpler les producteurs de données (capteurs) des consommateurs (dashboard, actionneurs), et la résilience requise face aux réseaux instables.

### 3.1 Le Broker Local : Résilience et Autonomie (simple_broker.py)

Le script simple_broker.py <sup>1</sup> instancie un serveur MQTT directement sur la BeagleY-AI.

**Pourquoi un broker local?**

Si la connexion internet coupe, le parking doit continuer à fonctionner : la barrière doit s'ouvrir si le ticket est valide, et les panneaux doivent afficher "LIBRE" ou "COMPLET". En hébergeant le broker sur la passerelle, on garantit que le trafic interne (STM32 \<-\> BeagleY-AI) reste fonctionnel en mode "îlotage".

**Analyse du Code :**

-   Le script utilise la bibliothèque amqtt (anciennement hbmqtt), qui repose sur asyncio pour une gestion non-bloquante des connexions.

-   **Configuration** :  
```python
config = {
'listeners': {
'default': {
'type': 'tcp',
'bind': '0.0.0.0:1883' # Écoute universelle
}
},
'auth': {
'allow_anonymous': True # Sécurité faible (Développement)
}
}
```

-   **Fonctionnement** : Il démarre une boucle d'événements asynchrone. La fonction broker.start() lance le service. Une boucle infinie while True: await asyncio.sleep(10) empêche le script de se terminer, maintenant le broker actif.

-   **Recommandation Sécurité** : En production, allow_anonymous doit impérativement passer à False. Un fichier de mots de passe doit être configuré pour que seuls le STM32 et les services internes (Bridge, Vision) puissent publier.

### 3.2 Le Pont vers le Cloud : Filtrage et Sécurité (mqtt_bridge.py)

Ce composant est la porte de sortie sécurisée vers internet. Il connecte le broker local (127.0.0.1) au broker cloud HiveMQ.<sup>1</sup> Les identifiants et paramètres de connexion du broker distant doivent être remplacés lors du paramétrage initial (voir section 3.3).

**Fonctionnalités Clés :**

1.  **Bridging Bidirectionnel** : Il maintient deux connexions client MQTT simultanées. Lorsqu'un message arrive sur l'une, il est republié sur l'autre, *sous condition*.

2.  **Sécurité TLS** : La connexion vers le cloud (broker.hivemq.com) se fait sur le port **8883** (MQTT over TLS). L'appel cloud.tls_set() active le chiffrement SSL/TLS, protégeant les données de stationnement et les commandes d'ouverture contre l'écoute ou l'injection sur le réseau public.

3.  **Filtrage par Whitelist (ACLs Logiques)** : C'est une fonctionnalité de sécurité applicative majeure.

    -   *Cloud vers Local (ALLOW_CLOUD_TO_LOCAL)* : Seules les commandes critiques sont autorisées (parking/barriere/cmd, parking/display/text). Cela empêche une compromission du cloud de devenir un vecteur d'attaque pour inonder le réseau local de messages parasites.

    -   *Local vers Cloud (ALLOW_LOCAL_TO_CLOUD)* : Seuls les états pertinents (parking/sensor_gate/present, parking/ascenseur/state) remontent. Les logs de debug ou le trafic haute fréquence inutile restent confinés localement, économisant la bande passante 4G/IoT.

### 3.3 Taxonomie des Topics (Namespace)

Une structure de topics rigoureuse est essentielle pour l'évolutivité. SysPark utilise une hiérarchie racine parking/.

| **Topic** | **Payload Exemple** | **QoS** | **Retain** | **Description** |
|---|---|---|---|---|
| parking/sensor_gate/present | 0 ou 1 | 1 | True | État du capteur de présence. Retain=True est crucial : un nouveau client (ex: dashboard) recevra immédiatement le dernier état connu à la connexion. |
| parking/display/text | "LIBRE: 12" | 0 | False | Message texte brut à afficher sur la matrice LED. |
| parking/barriere/cmd | "110" | 1 | False | Commande d'actionnement de la barrière. QoS 1 garantit la délivrance "au moins une fois". |
| parking/meteo | { "temp": 22,... }  | 0 | True | Données météorologiques agrégées pour affichage. |
| parking/system/heartbeat | Timestamp | 0 | False | Battement de cœur pour le monitoring de santé du système. |

## 4. Vision par Ordinateur : L'Intelligence Artificielle en Action

Le module beagle_vision_combined.py <sup>1</sup> transforme la BeagleY-AI d'une simple passerelle en un nœud de calcul intelligent. Il a pour mission de détecter les véhicules et de lire leurs plaques d'immatriculation (LAPI / ALPR - Automatic License Plate Recognition).

### 4.1 Pipeline d'Acquisition Vidéo (GStreamer & Hardware Acceleration)

Le traitement vidéo en 1080p est extrêmement gourmand. Une approche naïve utilisant OpenCV (cv2.VideoCapture) décoderait le flux via le CPU, saturant les 4 cœurs A53 et provoquant une surchauffe et une latence inacceptable (plusieurs secondes).

La solution adoptée exploite **GStreamer** et les éléments matériels dédiés de l'AM67A.<sup>12</sup>

```python
pipeline = (
"gst-launch-1.0 -q v4l2src device=/dev/video-imx219-cam0 io-mode=2 do-timestamp=true! "
"video/x-bayer,width=1920,height=1080,format=rggb,framerate=10/1! "
"tiovxisp sensor-name=SENSOR_SONY_IMX219_RPI...! "
"video/x-raw,format=NV12,width=1920,height=1080! "
"tiovxmultiscaler! "
"video/x-raw,format=NV12,width=640,height=360! "
"fdsink fd=1"
)
```

**Analyse du Pipeline :**

1.  **v4l2src** : Capture les données brutes (Raw Bayer) depuis le capteur via l'interface V4L2 (Video4Linux2).

2.  **tiovxisp (Texas Instruments OpenVX Image Signal Processor)** : C'est le cœur de l'optimisation. Cet élément décharge le CPU en confiant au **VPAC** les tâches lourdes :

    -   *Demosaicing* : Reconstruction des couleurs RGB à partir de la matrice de Bayer.

    -   *Auto White Balance (AWB) & Auto Exposure (AE)* : Ajustement dynamique de l'image (essentiel dans un parking où la luminosité varie).

    -   *Sortie NV12* : Format YUV semi-planaire, efficace pour la mémoire.

3.  **tiovxmultiscaler** : Redimensionnement matériel. L'image 1080p est réduite en 640x360, résolution d'entrée typique pour les réseaux de neurones (YOLO), sans coût CPU.

4.  **fdsink** : Redirige le flux binaire vers la sortie standard (Pipe), permettant à Python de lire les frames comme un fichier.

### 4.2 Architecture de Détection Hybride (YOLO + Tesseract)

Le script implémente une approche en deux temps pour la lecture de plaque :

1.  **Détection d'Objet (Localization) avec YOLOv8** :

    -   Le modèle best.pt (fine-tuné pour les plaques) est chargé via la librairie ultralytics.

    -   Il analyse l'image 640x360 et retourne une **Bounding Box** (coordonnées x, y, w, h) de la plaque.

    -   *Optimisation* : L'utilisation d'un modèle "Nano" (yolov8n) est recommandée sur ce type de hardware pour maintenir un framerate correct si l'accélération TIDL (TI Deep Learning) n'est pas pleinement configurée (le script semble utiliser l'inférence CPU par défaut d'Ultralytics, ce qui est un goulot d'étranglement potentiel).

2.  **Reconnaissance de Caractères (OCR) avec Tesseract** :

    -   La zone de la plaque (Region of Interest - ROI) est découpée dans l'image originale.

    -   **Prétraitement** : Conversion en niveaux de gris -\> Agrandissement (x2) -\> Binarisation (Otsu). Ces étapes sont cruciales pour "nettoyer" l'image avant l'OCR.

    -   **Inférence** : pytesseract extrait le texte.

    -   **Post-traitement (Heuristique SIV)** : Le script applique des règles métiers (Regex) pour valider le format AA-123-AA. Il corrige les erreurs OCR fréquentes (ex: un '0' détecté au début est remplacé par 'O' car le SIV commence par une lettre).

### 4.3 Streaming MJPEG (Feedback Visuel)

En parallèle de l'analyse, le script lance un serveur Flask léger sur le port **8000**. Il expose une route /mjpeg/cam1 qui diffuse les frames traitées.

-   **Utilisation** : Permet à l'opérateur de vérifier le cadrage de la caméra à distance via un navigateur Web, sans avoir besoin d'un flux vidéo complexe (RTSP/WebRTC).

-   **Mécanisme** : "Multipart/x-mixed-replace". Le navigateur reçoit une série d'images JPEG successives.

## 5. Interface Physique : Contrôle et Affichage

La BeagleY-AI n'est pas qu'un cerveau numérique, c'est aussi un contrôleur physique interagissant avec le monde réel via ses GPIOs et Bus série.

### 5.1 Affichage Matrix LED (Bus SPI Bas Niveau)

Le script bandeau_led.py <sup>1</sup> est une démonstration technique fascinante de programmation système en Python. Plutôt que d'utiliser une librairie abstraite (et lente) comme luma.core, il implémente une communication directe avec le driver noyau.

**Technique : ioctl et ctypes**

Le protocole SPI sous Linux est géré par le driver spidev. Pour envoyer des données efficacement (ex: animer une balle qui rebondit), il faut minimiser les changements de contexte (User space \<-\> Kernel space).

Le script définit la structure C spi_ioc_transfer via le module ctypes.

```python
class spi_ioc_transfer(ctypes.Structure):
_fields_ = [("tx_buf", ctypes.c_ulonglong),... ("speed_hz", ctypes.c_uint),...]
```

Il utilise ensuite fcntl.ioctl pour passer cette structure directement au noyau. Cela permet d'envoyer un buffer complet de pixels à 1 MHz en une seule opération atomique, garantissant une fluidité parfaite des animations de défilement de texte ("SCROLL LEFT").

**Logique Métier :**

-   L'affichage est piloté par MQTT. Sur réception de parking/display/text, le script met à jour son buffer interne.

-   Il gère des priorités : un message "COMPLET" (Parking plein) clignote pour attirer l'attention, tandis qu'un message "LIBRE" affiche le nombre de places avec une animation ludique.

### 5.2 Capteurs et Barrière (GPIO et Debouncing)

Le script sensor_gate.py <sup>1</sup> gère l'entrée binaire du capteur de présence.

**Problématique du Rebond (Bouncing) :**

Dans le monde réel, un signal électrique n'est jamais parfaitement propre. Lors d'une transition 0-\>1, le signal peut osciller plusieurs fois en quelques millisecondes. Une lecture naïve déclencherait de multiples événements "Véhicule entré / Véhicule sorti".

**Solution Logicielle** : Le script implémente un "Debounce" (anti-rebond) temporel. Un changement d'état n'est validé que s'il reste stable pendant STABLE_MS (300ms).

**Performance vs Facilité (subprocess vs libgpiod) :**

Le script actuel utilise :

```python
subprocess.check_output(["gpioget",...])
```

*Critique* : Cette méthode lance un nouveau processus shell Linux à chaque lecture (toutes les 50ms). C'est très lourd pour le CPU.

*Optimisation recommandée* : Utiliser les bindings Python de libgpiod (import gpiod) pour garder le périphérique GPIO ouvert et lire son état par simple appel de fonction C, divisant la charge CPU par 100.

**Sécurité (Fail-Safe)** :

Si la lecture échoue (erreur matérielle, surcharge CPU), le script force l'état "PRÉSENT". C'est une sécurité par défaut : le système préfère croire qu'il y a une voiture (et donc laisser la barrière ouverte ou interdire la fermeture) plutôt que de risquer un écrasement.

## 6. Services Tiers et Connectivité Étendue

SysPark ne vit pas en vase clos. Il s'appuie sur des services externes pour enrichir ses fonctionnalités et faciliter son administration.

### 6.1 Météo et Qualité de l'Air (OpenWeatherMap)

Le script meteo_client.py <sup>1</sup> interroge cycliquement (toutes les 60s) l'API OpenWeatherMap. La clé API doit être remplacée lors du paramétrage initial (voir section 3.3).

-   **Données** : Température, Pluie (pour avertir les motards par exemple), Vent, et Indice AQI (Qualité de l'Air).

-   **Flux** : Les données JSON reçues sont parsées ("flattened") et republiées sur MQTT (parking/meteo). Cela permet à l'affichage LED d'afficher "22°C - PLUIE" sans que la BeagleY-AI ait besoin de capteurs physiques coûteux. De plus, les données sont envoyées au serveur Cloud pour corréler la météo avec l'occupation du parking (Data Science).

### 6.2 Accès Distant Sécurisé (Tailscale)

Pour la télémaintenance (SSH, mise à jour des scripts, debug GStreamer), il est impensable d'exposer les ports de la BeagleY-AI directement sur Internet (Port Forwarding), surtout si le parking est connecté via un routeur 4G (CGNAT).

**Solution : Tailscale (VPN Mesh basé sur WireGuard)**.<sup>15</sup> Le nœud doit être rattaché au compte Tailscale de l'exploitant via une auth key (voir section 3.3).

-   **Principe** : La BeagleY-AI installe le démon tailscaled. Elle s'authentifie auprès du coordinateur Tailscale et crée une interface réseau virtuelle (ex: tailscale0 avec IP 100.x.y.z).

-   **Avantage** : Ce réseau est un "Overlay". L'ingénieur peut se connecter en SSH à l'IP 100.x.y.z depuis son PC (aussi sur Tailscale) comme s'il était sur le même réseau local, quel que soit l'endroit où se trouve le parking, traversant les pare-feux et NATs de manière transparente et chiffrée.

## 7. Déploiement Opérationnel et Maintenance

Pour transformer ce prototype en produit industriel fiable, l'installation doit être rigoureuse.

### 7.1 Gestion des processus (systemd)

Dans l’image SysPark, les services nécessaires sont déjà présents dans `/etc/systemd/system` et activés de manière à démarrer automatiquement. En exploitation, on évite de lancer les scripts à la main, et on passe systématiquement par systemd afin d’obtenir un redémarrage automatique, des logs centralisés (journald) et un comportement reproductible au reboot.

Les unités directement liées au projet SysPark sur BeagleY‑AI sont typiquement `simple_broker.service`, `mqtt_bridge.service`, `beagle_vision.service`, `bandeau_led.service`, `meteo_client.service`, `sensor_gate.service` et `servo_camera.service`.

Pour vérifier l’état d’un service et voir ses logs en direct, les commandes de référence sont :

```bash
systemctl status beagle_vision
journalctl -u beagle_vision -f
```

Même logique pour les autres services.

```bash
systemctl status simple_broker mqtt_bridge bandeau_led meteo_client sensor_gate servo_camera
```

Après modification d’un paramètre, redémarrer uniquement le service concerné, puis relire les logs pour valider.

```bash
systemctl restart mqtt_bridge
journalctl -u mqtt_bridge -n 100 --no-pager
```
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

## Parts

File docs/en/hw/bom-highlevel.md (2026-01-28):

Language: English | [Français](../../fr/hw/bom-highlevel.md)

# Hardware BOM (High-Level)

This document summarizes the SysPark hardware at block level. It is a field-oriented view meant for integration, wiring, and deployment planning. It does not replace detailed part datasheets.

SysPark is built around a clear separation:
- Edge gateway for orchestration and cloud bridge
- FPGA execution node for deterministic actuator control
- STM32 field nodes for real-time I/O close to equipment
- Optional vision node for plate recognition
- Power subsystem sized for motors and embedded compute

---

## 1) Core compute and control

### Edge gateway
- BeagleBone AI / BeagleY-AI class edge gateway
- Roles
  - MQTT broker (local bus)
  - Bridge to cloud services
  - Orchestration state machine
  - Remote maintenance entry point
  - Optional vision inference host

### FPGA execution node
- Digilent Nexys A7-100T FPGA board
- Roles
  - LiteX RISC-V soft SoC
  - Linux runtime for services
  - CSR-mapped I/O for actuator control
  - Deterministic control surface for barriers

### STM32 field nodes
- STM32F746G-DISCO boards
- Typical roles
  - Entry node: elevator or lane mechanism control, UI, RFID
  - Exit node: payment gating UI, RFID, network telemetry
- RTOS
  - Zephyr RTOS for deterministic multi-threading and Ethernet networking

---

## 2) Actuation hardware

### Barriers
- Barrier mechanisms for entry and exit lanes
- Drive chain in the demo setup
  - FPGA PMOD outputs
  - Driver stage (ULN2003 class)
  - Stepper motors (28BYJ-48 class) or equivalent small barrier actuator

### Elevator or lift mechanism (if used)
- Motorized lift for the demo platform
- Controlled by STM32 in real time
- Requires
  - motor driver matched to motor type
  - homing sensor or limit switch
  - mechanical end stops

---

## 3) Identification and user interfaces

### Identification
- RFID badge reader on STM32 nodes
- Optional vision-based plate recognition
  - camera per lane or shared camera depending on layout

### Local user feedback
- LCD 20x4 on STM32 for operator and lane prompts
- OLED display for lift or detailed status views
- LED banner display for driver-facing messages

---

## 4) Networking and interconnect

### Ethernet (preferred in SysPark)
- Edge gateway, FPGA node, STM32 nodes connected on a private LAN
- Switch or simple router in bridge mode

### Physical I/O wiring
- PMOD harness from FPGA to driver boards and sensors
- Sensor wiring to STM32 GPIO as needed

---

## 5) Power subsystem (high-level)

SysPark uses a centralized DC power architecture:
- Main battery rail (12 V class in the demo)
- DC-DC conversion to 5 V for compute and peripherals
- Additional local regulation to 3.3 V where required

Key blocks
- Battery pack
- BMS protection and balancing
- Primary fuse and wiring protection
- DC-DC 12 V to 5 V high current module
- Optional secondary DC-DC rails for specific actuators

---

## 6) Recommended spare parts for demos

Field demos fail on simple parts. Keep spares:
- Ethernet cables, small switch
- PMOD jumper wires and headers
- Motor drivers and spare motors
- RFID reader spare unit
- Fuses, connectors, cable ties
- SD cards for the FPGA Linux node

---

## 7) References

- Presentation PDF: references/pdf/SysPark_Présentation.pdf
- Power and BMS reference: references/pdf/BMS.pdf

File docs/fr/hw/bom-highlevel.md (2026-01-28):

Language: Français | [English](../../en/hw/bom-highlevel.md)

# BOM matériel (haut niveau)

Ce document résume le matériel SysPark par blocs. Il sert à l’intégration, au câblage et à la préparation déploiement. Il ne remplace pas les datasheets.

SysPark repose sur une séparation claire :
- passerelle edge pour orchestration et bridge cloud
- nœud exécution FPGA pour contrôle actionneurs déterministe
- nœuds STM32 terrain pour temps réel proche équipements
- vision optionnelle pour lecture plaque
- sous-système puissance dimensionné pour moteurs et compute

---

## 1) Calcul et contrôle

### Passerelle edge
- BeagleBone AI / BeagleY-AI (classe passerelle edge)
- Rôles
  - broker MQTT local
  - bridge vers le cloud
  - machine d’états d’orchestration
  - accès maintenance
  - hôte vision optionnel

### Nœud exécution FPGA
- Digilent Nexys A7-100T
- Rôles
  - SoC soft LiteX RISC-V
  - Linux pour services
  - I/O CSR pour actionnement
  - surface de contrôle déterministe pour barrières

### Nœuds STM32
- STM32F746G-DISCO
- Rôles typiques
  - entrée : mécanisme ascenseur, UI, RFID
  - sortie : UI paiement, RFID, télémétrie réseau
- RTOS
  - Zephyr RTOS pour multi-threads déterministes et Ethernet

---

## 2) Actionnement

### Barrières
- mécanismes barrière entrée et sortie
- chaîne démo
  - sorties PMOD FPGA
  - étage driver (type ULN2003)
  - moteurs pas-à-pas (classe 28BYJ-48) ou équivalent

### Ascenseur ou lift (si utilisé)
- mécanisme motorisé pour la maquette
- piloté par STM32 en temps réel
- nécessite
  - driver moteur adapté
  - fin de course homing
  - butées mécaniques

---

## 3) Identification et interfaces

### Identification
- lecteur badge RFID sur STM32
- vision lecture plaque optionnelle
  - caméra par voie ou caméra partagée selon layout

### Feedback local
- LCD 20x4 sur STM32 pour prompts et statut
- OLED pour statut ascenseur ou debug
- bandeau LED pour messages conducteur

---

## 4) Réseau et interconnexions

### Ethernet (préféré)
- passerelle, FPGA, STM32 connectés sur un LAN privé
- switch ou routeur en mode bridge

### I/O physiques
- faisceaux PMOD FPGA vers drivers et capteurs
- capteurs vers GPIO STM32 selon besoin

---

## 5) Puissance (haut niveau)

Architecture puissance DC centralisée :
- rail batterie (classe 12 V en démo)
- conversion DC-DC vers 5 V pour compute et périphériques
- régulation locale vers 3.3 V si nécessaire

Blocs clés
- pack batterie
- BMS protection et équilibrage
- fusible principal et protection câbles
- DC-DC 12 V vers 5 V fort courant
- rails secondaires optionnels selon actionneurs

---

## 6) Consommables à prévoir pour les démos

Les démos tombent souvent sur des détails. Garder en spare :
- câbles Ethernet, petit switch
- jumpers PMOD et headers
- drivers moteurs et moteurs de rechange
- lecteur RFID de rechange
- fusibles, connecteurs, colliers
- cartes SD pour le nœud Linux FPGA

---

## 7) Références

- Présentation : references/pdf/SysPark_Présentation.pdf
- Puissance et BMS : references/pdf/BMS.pdf

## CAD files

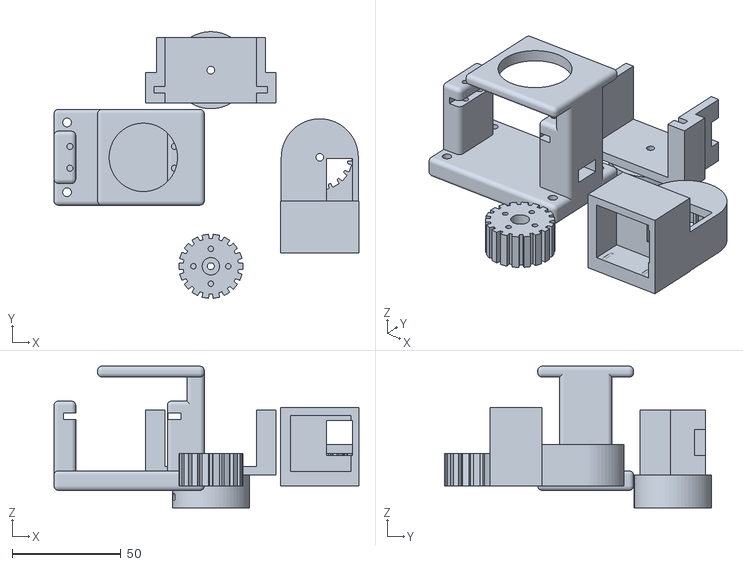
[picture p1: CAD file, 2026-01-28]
assets/meca/Camera CSI/support_only.stl
140.0 x 122.4 x 65.0

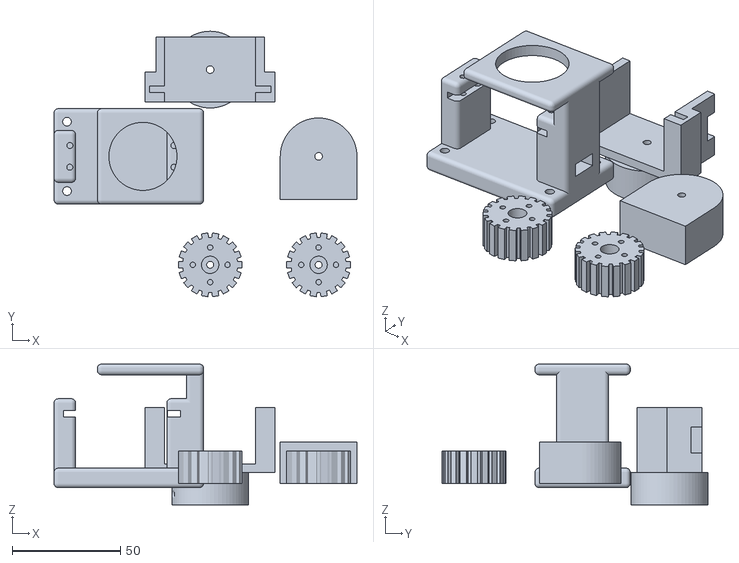
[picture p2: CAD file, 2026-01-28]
assets/meca/camera Logitec/support_camera_logitec.stl
139.7 x 122.4 x 65.0

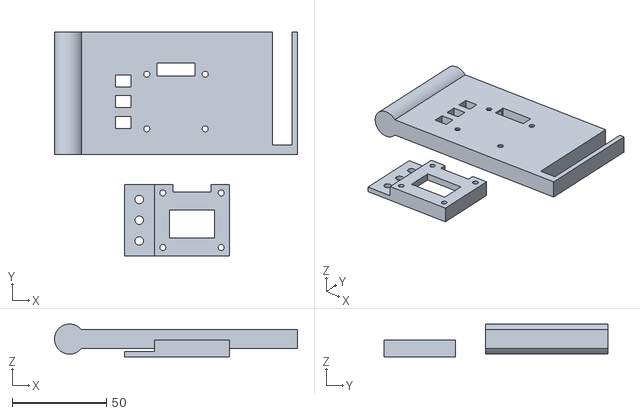
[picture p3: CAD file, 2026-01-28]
assets/meca/Ecran OLED ascenseur/ecran_ascenseur_V3.stl
129.0 x 119.1 x 17.5

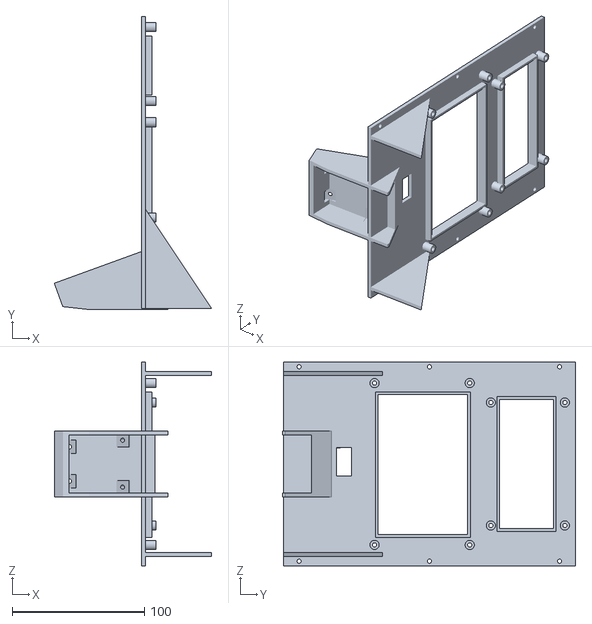
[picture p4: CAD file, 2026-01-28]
assets/meca/Support stm+rfid+lcd/stm32_suppport_avant.stl
119.1 x 221.6 x 154.0

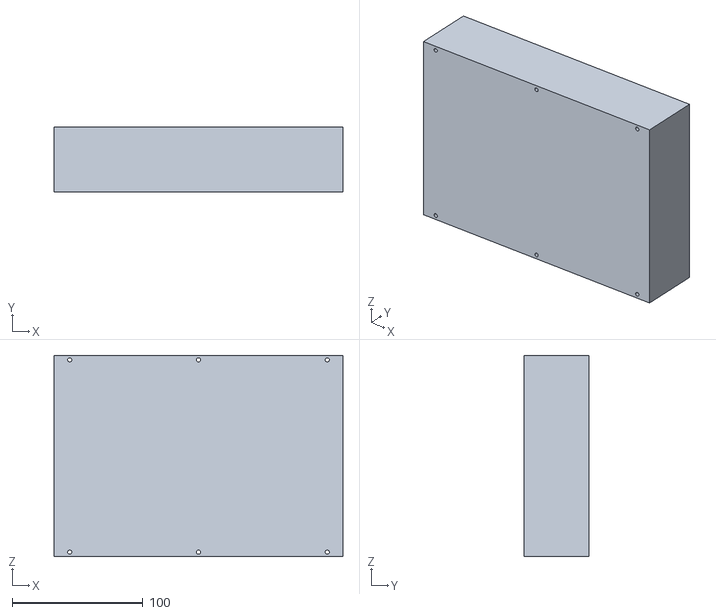
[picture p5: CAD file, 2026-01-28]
assets/meca/Support stm+rfid+lcd/stm32_suppport_arriere.stl
221.0 x 50.0 x 154.0

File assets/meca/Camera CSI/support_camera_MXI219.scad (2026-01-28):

// ==============================================
// PARAMETRES ET CONFIGURATION
// ==============================================

// METTRE A 'true' POUR IMPRIMER (STL)
// METTRE A 'false' POUR VOIR L'ASSEMBLAGE
mode_impression = true; 

// --- PARAMETRES DE PRECISION ---
$fn = 60; 
tol = 0.4; 

// --- VISSERIE ---
m3_hole = 3.2; 
m2_hole = 2.2; 
servo_screw_head_d = 7.0; 

// --- DIMENSIONS MATERIEL (Hitec HS-422) ---
s_len = 40.6;
s_wid = 20.0;
s_hgt = 37.0; 
s_tab_len = 54.0; 
hole_ax_L = 48.0; 
hole_ax_W = 10.0; 
wall = 4.0; 

// --- DIMENSIONS ECROU M3 ---
m3_nut_h = 3.0; 
m3_nut_w = 6.0; 

// --- DIMENSIONS PIGNON (GREEN GEAR - 18 DENTS) ---
pinion_pd = 25.4; // Diamètre primitif
pinion_teeth = 18;
pinion_h = 15.0; 
// Diametre hors-tout approximatif pour les trous de passage (base)
gear_outer_d = pinion_pd + 4.0; 

// --- DIMENSIONS CAMERA (ArduCam 8MP Cube) ---
cam_cube_side = 28.0; 
cam_cube_depth = 20.0; 
cam_lens_d = 9.0; 
cam_hole_dist = 21.0; 

// Dimensions connecteur FAKRA (Bleu)
fakra_d = 12.0; 

c_servo = "red";

// --- DIMENSIONS STRUCTURE ---
base_L = 65; 
base_W = 40;
base_X_start = 30; 

// ==============================================
// MODULES
// ==============================================

module dummy_servo(show_gear=true) {
    difference() {
        union() {
            color(c_servo) {
                cube([s_len, s_wid, s_hgt], center=true);
                translate([0, 0, 10]) cube([s_tab_len, s_wid, 2.5], center=true); 
            }
            color("white") translate([10, 0, s_hgt/2]) 
                cylinder(d=6, h=6); 
            
            // Affiche le Pignon Vert (18 dents)
            if(show_gear) {
                translate([10, 0, s_hgt/2 + 2]) 
                color("Lime")
                union() {
                    cylinder(d=pinion_pd, h=pinion_h); 
                    for(i=[0:360/pinion_teeth:360]) rotate([0,0,i]) 
                        translate([pinion_pd/2-1, -1.5, 0]) cube([3, 3, pinion_h]);
                }
            }
        }
        for(i=[-1,1]) for(j=[-1,1]) {
             translate([i*hole_ax_L/2, j*hole_ax_W/2, 10])
                cylinder(d=m3_hole, h=10, center=true); 
        }
    }
}

module part_base() {
    difference() {
        union(){
            minkowski() { translate([base_X_start, -base_W/2, 0]) cube([base_L, base_W, 5]); sphere(r=2); }
            minkowski() { translate([30, -10, 0]) cube([6,20,37]); sphere(r=2); }
            minkowski() { translate([82, -10, 0]) cube([13,20,37]); sphere(r=2); }
            minkowski() { translate([91, -10, 37]) cube([4,20,16]); sphere(r=2); }
            difference() {
                minkowski() { translate([50, -20, 52]) cube([45,40,1]); sphere(r=2); }
                // Adaptation trou pour le pignon vert
                translate([69, 0, 50]) cylinder(h=37, d=gear_outer_d + 2); 
            }
        }
        translate([59.3, 0, 0]) { 
            for(i=[-1,1]) for(j=[-1,1]) {
                translate([i*hole_ax_L/2, j*hole_ax_W/2, 35]) cylinder(d=2.8, h=30, center=true); 
            }
        }
        translate([base_X_start + base_L/2, 0, 0]) { 
            for(i=[-1,1]) for(j=[-1,1]) {
                translate([i*(base_L/2 - 4), j*(base_W/2 - 4), 0]) cylinder(d=4, h=50, center=true); 
            }
        }
        translate([59.3, 0, 0]) { 
            for(i=[-1,1]) for(j=[-1,1]) {
                translate([i*hole_ax_L/2, j*hole_ax_W/2, 32]) cube([m3_nut_w, 20, m3_nut_h], center=true);
            }
        }
        translate([80, 0, 15]) cube([40, 12, 6], center=true);
    }
}

module part_u_bracket() {
    u_width_inside = s_wid + 1; 
    bracket_H = 50;
    center_offset_X = -bracket_H/2; 
    
    // Adaptation au pignon vert
    cup_wall = 3; 
    cup_OD = pinion_pd + 2*cup_wall + 4; // Un peu plus large pour la solidité
    
    slot_w = s_wid + 1.0; 
    
    difference() {
        union() {
            // Corps de la cloche (Hub)
            translate([0,0, -pinion_h + 5]) cylinder(h=pinion_h, d=cup_OD);
            cylinder(h=5, d=cup_OD);
            
            // Bras du U
            translate([center_offset_X, -15, 5]) {
                cube([bracket_H, 30, wall]); 
                translate([0, 0, 0]) cube([wall, 30, u_width_inside + wall + 5]);
                translate([-5, 0, 0]) cube([6, 14, u_width_inside + wall + 5]);
                translate([bracket_H-wall, 0, 0]) cube([wall, 30, u_width_inside + wall + 5]); 
                translate([bracket_H-wall+3, 0, 0]) cube([6, 14, u_width_inside + wall + 5]);
            }
        }
        
        // --- SOUSTRACTION DU PIGNON VERT (EMBOITEMENT) ---
        // On reproduit la forme du pignon en négatif avec tolérance
        translate([0,0, -pinion_h + 5 - 0.1]) {
             cylinder(d=pinion_pd + tol, h=pinion_h + 0.1); 
             for(i=[0:360/pinion_teeth:360]) rotate([0,0,i]) 
                translate([pinion_pd/2-1 - tol/2, -1.5 - tol/2, 0]) 
                cube([3 + tol, 3 + tol, pinion_h + 0.1]);
        }
        
        // Fentes verticales
        translate([center_offset_X - 1, -slot_w/2, 5 + wall + s_wid/2 -10]) cube([wall+2, 3, 50]); 
        translate([center_offset_X + bracket_H - wall - 1, -slot_w/2, 5 + wall + s_wid/2 -10]) cube([wall+2, 3, 50]); 
        
        // Trou central vis
        translate([0,0, -20]) cylinder(h=50, d=3.5); 
        
        // Trous fixation servo 2
        translate([center_offset_X - 1, 0, 5 + wall + s_wid/2]) rotate([0,90,0]) {
             translate([hole_ax_L/2, 0, 0]) cylinder(h=10, d=3.5);
             translate([-hole_ax_L/2, 0, 0]) cylinder(h=10, d=3.5);
             translate([hole_ax_L/2, hole_ax_W/2, 0]) cylinder(h=10, d=3.5);
             translate([hole_ax_L/2, -hole_ax_W/2, 0]) cylinder(h=10, d=3.5);
             translate([-hole_ax_L/2, hole_ax_W/2, 0]) cylinder(h=10, d=3.5);
             translate([-hole_ax_L/2, -hole_ax_W/2, 0]) cylinder(h=10, d=3.5);
        }
        
        // Trou passage cable tilt
        translate([22, 13, 20]) cube([10, 6, 12], center=true);
    }
}

module part_pinion_gear() {
    pd = pinion_pd; 
    teeth = pinion_teeth; 
    
    difference() {
        union() {
            cylinder(d=pd, h=pinion_h); 
            for(i=[0:360/teeth:360]) rotate([0,0,i]) translate([pd/2-1, -1.5, 0]) cube([3, 3, pinion_h]);
        }
        cylinder(d=8, h=20, center=true); 
        for(r=[0:90:360]) rotate([0,0,r]) translate([8,0,0]) cylinder(d=2.5, h=20, center=true);
            
    translate([0,0,-0.5])
            cylinder(d=m3_hole, h=pinion_h+1);
    }
    
}

module part_camera_mount_fitted() {
    pd = pinion_pd; 
    teeth = pinion_teeth; 
    
    // Dimensions du moyeu (hub)
    hub_d = pd + 10 ; 
    hub_h = 15;
    
    // Dimensions du boîtier caméra
    box_w = cam_cube_side + 2*wall;
    box_h = cam_cube_side + 2*wall;
    box_d = cam_cube_depth + wall; 
    
    // Distance du centre du servo au début du boîtier
    arm_len = 20; 
    
    difference() {
        union() {
            // 1. Le Moyeu (Hub)
            cylinder(d=hub_d, h=hub_h + wall); 
            
            // 2. Le Bras de liaison
            translate([-hub_d/2, -arm_len, 0]) 
                cube([hub_d, arm_len, hub_h + wall]);
                
            // 3. Le Boîtier Caméra
            translate([-box_w/2, -arm_len - box_d, 0]) {
                cube([box_w, box_d, box_h]);
            }
        }
        
        // --- A. SOUSTRACTION DU PIGNON ---
        translate([0,0, -0.1]) {
            cylinder(d=pd + tol, h=hub_h + 0.1); 
            for(i=[0:360/teeth:360]) rotate([0,0,i]) 
                translate([pd/2-1 - tol/2, -1.5 - tol/2, 0]) 
                cube([3 + tol, 3 + tol, hub_h + 0.1]);
        }
        translate([0,0, -5]) cylinder(d=3.5, h=50);
        
        // --- B. LOGEMENT CAMERA ---
        translate([-cam_cube_side/2 - tol +1, -arm_len - box_d - 1, box_h/2 - cam_cube_side/2 - tol+3]) {
             cube([cam_cube_side + 2*tol -1, cam_cube_depth + 2*tol -6, cam_cube_side + 2*tol -3]);
        }
        
        // --- C. TROU OBJECTIF ET FIXATIONS ---
        translate([0, -arm_len - box_d + wall, box_h/2]) rotate([90,0,0]) {
            cylinder(d=cam_lens_d, h=wall+2, center=true);
            for(i=[-1,1]) for(j=[-1,1]) {
                translate([i*cam_hole_dist/2, j*cam_hole_dist/2, 0])
                    cylinder(d=2.2, h=wall+2, center=true);
            }
        }
        
        // --- D. PASSAGE CABLE FAKRA ---
        translate([9, -arm_len/2 - box_d -5, box_h/2+4]) 
            rotate([90,0,0])
            cube([fakra_d, fakra_d+4, 77], center=true); 
    }
}


// ==============================================
// VISUALISATION / GENERATION
// ==============================================

if (mode_impression) {
    // --- DISPOSITION A PLAT POUR IMPRESSION 3D ---
    
    // 1. La Base
    part_base();

    // 2. Le U-Bracket (décalé)
    translate([100, 40, 0]) 
        part_u_bracket();
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

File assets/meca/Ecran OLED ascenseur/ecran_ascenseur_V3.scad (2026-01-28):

// --- PARTIE 1 : PARAMÈTRES ---
$fn = 50;

// --- PARAMÈTRES BOUTONS ---
btn_total_h = 8.0;   
btn_cyl_h   = 6.0;   
btn_stick_out = 3.0; 

facade_thick = btn_cyl_h - btn_stick_out; 

btn_body_size = 6.4; 
btn_body_size_largeur = 8;
btn_cyl_dia = 4.5;   
btn_vertical_spacing = 11; 
btn_x_offset = 28;   
side_panel_w = 18;   

// --- PARAMÈTRES OLED ---
pcb_width = 35.5;
pcb_height = 33.7; 
screen_width = 24;   
screen_height = 15;
screen_offset_y = -2; 

// Trous recentrés
hole_dist_x = 31.0; 
hole_dist_y = 29.0; 

// Diamètre vis M3
hole_dia = 3.2;     

// --- PARAMÈTRES BOÎTIER ---
wall_thick = 2.0;
inner_depth_oled = 6; 
tolerance = 0.4;

// Passage de câbles élargi
pin_cutout_width = 20; 

total_oled_h = facade_thick + inner_depth_oled;

// --- NOUVEAUX PARAMÈTRES DE DIMENSION (CORRECTION -1CM) ---
// Ancienne longueur : 136. Nouvelle : 126.
base_length = 126; 

// Position GLOBALE (Adaptée à la nouvelle longueur)
// On décale l'écran de 10mm vers la gauche pour garder les proportions
oled_global_x = 61.5; // Était 71.5
oled_global_z = 60 - 23;   
oled_rot = [90, 180, 0];


// --- MODULES (Formes) ---

module shape_boitier_solid(marge=0) {
    outer_w = pcb_width + (wall_thick * 2) + tolerance;
    outer_h = pcb_height + (wall_thick * 2) + tolerance;

    union() {
        cube([outer_w + marge, outer_h + marge, total_oled_h], center=true);
        translate([ (outer_w/2) + (side_panel_w/2) - 2, 0, (total_oled_h/2) - (facade_thick/2)]) 
            cube([side_panel_w + marge, outer_h + marge, facade_thick], center=true);
    }
}

module oled_case_gray() {
    outer_w = pcb_width + (wall_thick * 2) + tolerance;
    outer_h = pcb_height + (wall_thick * 2) + tolerance;

    difference() {
        shape_boitier_solid(marge=0);

        // Interieur
        translate([0, 0, facade_thick])
            cube([pcb_width + tolerance, pcb_height + tolerance, inner_depth_oled + 1], center=true);
        translate([0, screen_offset_y, 0])
            cube([screen_width, screen_height, total_oled_h + 2], center=true);
        
        // Trous Vis
        for (x = [-1, 1], y = [-1, 1]) {
            translate([x * (hole_dist_x / 2), y * (hole_dist_y / 2), 0])
                cylinder(d=hole_dia, h=total_oled_h + 2, center=true);
        }
        
        // Passage nappe
        translate([0, (outer_h/2), 0])
            cube([pin_cutout_width, wall_thick * 4, total_oled_h * 2], center=true);

        // Boutons
        for (i = [-1, 0, 1]) {
            translate([btn_x_offset, i * btn_vertical_spacing, (total_oled_h/2) - (facade_thick/2)]) {
                cylinder(d=btn_cyl_dia, h=facade_thick*3, center=true);
            }
        }
    }
}

module holes_in_green_support() {
    // Trous vis traversants
    for (x = [-1, 1], y = [-1, 1]) {
        translate([x * (hole_dist_x / 2), y * (hole_dist_y / 2), 0])
            cylinder(d=hole_dia, h=50, center=true); 
    }
    
    // Passage nappe traversant
    translate([0, 17, 0]) 
        cube([pin_cutout_width, 7, 50], center=true);
        
    for (i = [-1, 0, 1]) {
        translate([btn_x_offset, i * btn_vertical_spacing, 0])
            cube([btn_body_size_largeur, btn_body_size, 50], center=true); 
    }
}

module support_base() {
    rod_x = 5;      
    rod_y = 5;      
    rod_dia = 11;   
    boss_dia = 16;  

    difference() {
        union() {
            // MODIFICATION ICI : Longueur passée à base_length (126mm)
            color("Green") translate([0, 0, 0]) cube([base_length, 10, 65]);
            translate([rod_x, rod_y, 65/2]) 
                cylinder(d=boss_dia, h=65, center=true);
        }
        
        // MODIFICATION ICI : Décalage de l'encoche de fin (-10mm)
        // Ancienne pos : 122.7. Nouvelle : 112.7 pour suivre la réduction
        translate([112.7, -5, 0]) cube([10.3, 20, 60]); 
        
        translate([rod_x, rod_y, 0]) 
            cylinder(d=rod_dia, h=120, center=true); 
    }
}

// --- MISE EN PLACE POUR IMPRESSION (PLATEAU) ---

offset_flush = -(total_oled_h / 2);

union() {
    
    // PIÈCE 1 : Le Support Vert (Couché sur le dos)
    translate([0, 0, 0]) 
    rotate([90, 0, 0])   
    difference() {
        support_base();
        
        // On recrée les trous avec la marge de 0.4mm
        translate([oled_global_x, 0, oled_global_z]) 
        rotate(oled_rot) {
            translate([0, 0, offset_flush]) 
                shape_boitier_solid(marge=0.4); 
            translate([0, 0, -10])
                holes_in_green_support();
        }
    }

    // PIÈCE 2 : Le Boîtier Gris (Façade contre plateau)
    translate([70, -100, 0]) 
    rotate([0, 180, 0]) 
        oled_case_gray();
}

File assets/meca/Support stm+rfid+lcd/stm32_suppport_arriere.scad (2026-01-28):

// --- PARAMÈTRES ---
$fn = 50;

// 1. DIMENSIONS EXACTES (Vos réglages validés)
pcb_w = 130.0;
pcb_h = 80.0;

// Positions exactes centres des 4 trous STM32 : 3.8 mm des bords G/D et 4 mm des bords H/B
hole_x   = (pcb_w / 2) - 3.8;   // = 65 - 3.8 = 61.2
pos_y_top = (pcb_h / 2) - 4.0;  // = 40 - 4 = 36
pos_y_bot = -((pcb_h / 2) - 4.0); // = -36

// LCD secondaire (infos places + météo/CO2)
lcd2_w = 98.0;
lcd2_h = 60.0;
lcd2_depth = 22.0;

lcd2_clearance = 0.4;     // jeu par côté
lcd2_frame_wall = 2.0;    // épaisseur du cadre de maintien
lcd2_ext_margin = 6.0;    // marge autour dans l’extension
lcd2_gap = 5.0;           // distance entre haut de plaque STM32 et fenêtre LCD2

mount_side = 7.0;   // +7 mm à gauche et +7 mm à droite pour zone de vissage arrière

// 2. ÉCRAN
screen_w = 105.0;
screen_h = 67.0;
screen_offset_y = 3.0; 

// 3. PARAMÈTRES DU STAND VERTICAL
plate_margin = 5.0; 
plate_thick = 3.0;  
spacer_h = 6.0;     
tilt_angle = 15;    // Inclinaison en arrière (degrés)
foot_depth = 60;    // Profondeur du pied

// Dimensions RFID RC522
pcb_width = 40;
pcb_height = 60;
hole_dist_x = 33; 
hole_dist_y = 54;
pcb_thickness = 1.6;

// Paramètres du boîtier
angle = 20;
wall_thick = 3.0;       // Épaisseur des murs extérieurs
front_layer = 0.8;      // Épaisseur de la façade (FIN pour bien capter !)
internal_depth = 15;    // Place pour les composants et les fils
cable_slot_w = 21.3;    // Largeur du trou pour les câbles


// --- MODULE PRINCIPAL (RFID) ---
module rfid_console_embedded() {
    
    // Dimensions totales du bloc
    box_w = pcb_width + (wall_thick * 2) + 4; // +4mm de marge
    box_h = pcb_height + (wall_thick * 2) + 4;
    box_d = internal_depth + front_layer + wall_thick; // Profondeur totale locale
    
    difference() {
        // 1. LE VOLUME EXTÉRIEUR (Le Pupitre)
        hull() {
            translate([0, 0, sin(angle)*box_h/2]) 
            rotate([angle, 0, 0])
                cube([box_w, box_h, box_d], center=true);

            translate([0, 20, -10])
                cube([box_w, 60, 2], center=true);
        }

        // 2. L'ÉVIDEMENT INTERNE (LA POCHE)
        translate([0, 0, sin(angle)*box_h/2]) 
        rotate([angle, 0, 0]) {
            translate([0, 0, front_layer+10+6.5]) 
                cube([pcb_width + 2, pcb_height + 2, box_d], center=true);

            translate([1.6, box_h/2 - 5+2, 0+5+5.4])
                cube([cable_slot_w, 10, 9], center=true);
        }

        // 3. TROU ARRIÈRE GLOBAL
        translate([0, 20, -4]) cube([box_w - 6, 90, 30], center=true);

        // 4. TROUS DE FIXATION TRAVERSANTS + POCHES ECROUS
        translate([0, 0, sin(angle)*box_h/2]) 
        rotate([angle, 0, 0]) {

            xL = -pcb_width/2;
            xR =  pcb_width/2;
            yB = -pcb_height/2;
            yT =  pcb_height/2;

            // ---- TROUS M3 PASSANTS ----
            translate([xL + 7.0,  yB + 6.8, 0])
                cylinder(d=3.2, h=box_d + 5, center=false);

            translate([xR - 7.0,  yB + 6.8, 0])
                cylinder(d=3.2, h=box_d + 5, center=false);

            translate([xR - 2.0,  yT - 15.0, -10])
                cylinder(d=3.2, h=box_d + 5, center=false);

            translate([xL + 2.5,  yT - 15.0, -10])
                cylinder(d=3.2, h=box_d + 5, center=false);

            // ---- POCHES POUR ECROUS ----
            nut_pocket_xy = 10;
            nut_pocket_z  = 6;
            nut_pocket_zc = -box_d/2 + 2;

            translate([xL + 7.0,  yB + 6.8, nut_pocket_zc+12])
                cube([nut_pocket_xy, nut_pocket_xy, nut_pocket_z], center=true);

            translate([xR - 7.0,  yB + 6.8, nut_pocket_zc+12])
                cube([nut_pocket_xy, nut_pocket_xy, nut_pocket_z], center=true);

            translate([xR - 2.0,  yT - 15.0, nut_pocket_zc])
                cube([nut_pocket_xy, nut_pocket_xy, nut_pocket_z], center=true);

            translate([xL + 2.5,  yT - 15.0, nut_pocket_zc])
                cube([nut_pocket_xy, nut_pocket_xy, nut_pocket_z], center=true);
        }
    }
}


// --- MODULE 1 : LA FAÇADE COMPLÈTE (Plaque + Trous + Piliers) ---
module head_assembly() {

    // Jeu (par côté) pour insertion
    screen_clearance = 0.4;

    // Écran principal : cadre arrière
    screen_depth = 5.0;
    screen_frame_wall = 2.0;

    // Centre découpe écran principal (coin sup droit : 12 mm du bord droit, 6 mm du bord haut)
    screen_cx = (pcb_w/2) - (screen_w/2) - 12;
    screen_cy = (pcb_h/2) - (screen_h/2) - 6;

    // LCD2 : fenêtre visible (97x40) + rebord intérieur 5mm
    lcd2_screen_w = 97.0;
    lcd2_screen_h = 40.0;

    // Placement fenêtre visible LCD2 : coin inférieur gauche à 0.5 mm du bord gauche et 9 mm du bas
    lcd2_screen_off_left = 0.5;
    lcd2_screen_off_bottom = 9.0;

    // Trous LCD2 (M3) : centre à 2.5 mm du bord gauche/droit et 2 mm du bas/haut
    lcd2_hole_off_x = 2.5;
    lcd2_hole_off_y = 2.0;
    lcd2_hole_d = 3.5;

    // Dimensions plaque (élargie)
    plate_w_base = pcb_w + 2*plate_margin;
    plate_w      = plate_w_base + 2*mount_side;
    plate_h      = pcb_h + 2*plate_margin;

    plate_top = (pcb_h/2) + plate_margin;
    lcd2_cx = 0;
    lcd2_cy = plate_top + lcd2_gap + (lcd2_h/2);

    // Extension LCD2 : même largeur que la plaque STM32
    ext_w = plate_w;
    ext_h = lcd2_h + 2*lcd2_ext_margin;

    // Vis boitier avant <-> arrière
    case_screw_d    = 3.2;
    case_screw_edge = 12.0;
    case_screw_x = (plate_w/2) - (mount_side/2);

    case_screw_y1 = -(plate_h/2) + case_screw_edge - 60;
    case_screw_y3 = (lcd2_cy + ext_h/2) - case_screw_edge;
    case_screw_y2 = (case_screw_y1 + case_screw_y3) / 2;

    // Bords LCD2
    lcd2_xL = lcd2_cx - lcd2_w/2;
    lcd2_xR = lcd2_cx + lcd2_w/2;
    lcd2_yB = lcd2_cy - lcd2_h/2;
    lcd2_yT = lcd2_cy + lcd2_h/2;

    // Centre fenêtre visible LCD2
    lcd2_screen_cx = lcd2_xL + lcd2_screen_off_left + (lcd2_screen_w/2);
    lcd2_screen_cy = lcd2_yB + lcd2_screen_off_bottom + (lcd2_screen_h/2);

    // Rebord intérieur LCD2
    lcd2_screen_depth = 5.0;
    lcd2_screen_frame_wall = 2.0;

    union() {

        // A. Plaque + découpes
        difference() {

            union() {
                // Corps principal (STM32)
                translate([0, 0, plate_thick/2])
                    cube([plate_w, plate_h, plate_thick], center=true);

                // Extension LCD2
                translate([lcd2_cx, lcd2_cy, plate_thick/2])
                    cube([ext_w, ext_h, plate_thick], center=true);

                // Pattes latérales descendantes
                total_h = plate_h + (lcd2_gap + lcd2_h + 2*lcd2_ext_margin + 53);

                for (sx = [-1, 1]) {
                    translate([sx * (plate_w/2 - mount_side/2), (lcd2_cy - ext_h/2)/2 - 17, plate_thick/2])
                        cube([mount_side, total_h, plate_thick], center=true);
                }
            }

            // Découpe écran principal
            translate([screen_cx, screen_cy, 0])
                cube([screen_w + 2*screen_clearance,
                      screen_h + 2*screen_clearance,
                      plate_thick + 10], center=true);

            // Fenêtre LCD2
            translate([lcd2_screen_cx, lcd2_screen_cy, 0])
                cube([lcd2_screen_w + 2*screen_clearance,
                      lcd2_screen_h + 2*screen_clearance,
                      plate_thick + 10], center=true);

            // Trous fixation STM32 (M3)
            for (sx = [-1, 1]) for (sy = [-1, 1]) {
                translate([ sx * (pcb_w/2 - 3.8),  sy * (pcb_h/2 - 4.0), 0 ])
                    cylinder(d=3.5, h=20, center=true);
            }

            // Trous fixation LCD2 (M3)
            for (hx = [lcd2_xL + lcd2_hole_off_x, lcd2_xR - lcd2_hole_off_x])
            for (hy = [lcd2_yB + lcd2_hole_off_y, lcd2_yT - lcd2_hole_off_y]) {
                translate([hx, hy, 0])
                    cylinder(d=lcd2_hole_d, h=20, center=true);
            }

            // Trous boitier avant/arrière (6x M3)
            for (sx = [-1, 1])
            for (yy = [case_screw_y1, case_screw_y2, case_screw_y3]) {
                translate([sx * case_screw_x, yy, 0])
                    cylinder(d=case_screw_d, h=30, center=true);
            }
        }

        // B. Cadre arrière écran principal (5 mm)
        translate([screen_cx, screen_cy, plate_thick + screen_depth/2])
        difference() {
            cube([(screen_w + 2*screen_clearance) + 2*screen_frame_wall,
                  (screen_h + 2*screen_clearance) + 2*screen_frame_wall,
                  screen_depth], center=true);

            cube([(screen_w + 2*screen_clearance),
                  (screen_h + 2*screen_clearance),
                  screen_depth + 0.2], center=true);
        }
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

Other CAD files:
assets/meca/camera Logitec/support_camera_logitec.scad
assets/meca/Support stm+rfid+lcd/stm32_suppport_avant.scad

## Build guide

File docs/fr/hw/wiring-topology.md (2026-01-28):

Language: Français | [English](../../en/hw/wiring-topology.md)

# Topologie de câblage et faisceaux

Le câblage SysPark se sépare en deux catégories :
- puissance pour batterie, DC-DC et moteurs
- signaux pour Ethernet et I/O basse tension

Ce document donne une stratégie câblage propre pour une démo fiable.

---

## 1) Principe de layout

Séparer physiquement les blocs :
- bloc puissance
  - batterie, BMS, DC-DC, fusible
- bloc compute
  - passerelle, FPGA, STM32, switch
- bloc actionnement
  - drivers moteurs, moteurs, fins de course, mécanismes
- bloc vision
  - caméra et support

Cela réduit le couplage bruit et simplifie le debug.

---

## 2) Câblage Ethernet

Topologie préférée
- un petit switch Ethernet sur la maquette
- connexions en étoile
  - passerelle
  - FPGA
  - STM32 entrée
  - STM32 sortie
  - PC opérateur optionnel

Règles
- câbles courts et fixés
- éviter Ethernet proche des drivers pas-à-pas
- étiqueter chaque câble par rôle

---

## 3) PMOD FPGA (actionnement et capteurs)

Le PMOD est sensible à l’ordre des pins.

Bonnes pratiques
- un PMOD dédié sorties vers drivers
- un PMOD dédié entrées capteurs
- convention couleurs cohérente
  - power
  - ground
  - signaux 0..7

Checks intégration
- test continuité de chaque ligne
- valider sens IN ou OUT
- éviter entrées flottantes

---

## 4) Drivers et moteurs

Exemple chaîne pas-à-pas
- sorties FPGA vers entrées driver
- sorties driver vers phases moteur

Règles
- torsader les câbles moteurs
- éloigner des câbles Ethernet et caméra
- strain relief près des parties mobiles
- protection mécanique contre frottement câble

---

## 5) Câblage STM32

Câblage typique par nœud
- Ethernet
- interface lecteur RFID
- écrans UI
- interface driver moteur lift
- fin de course et entrées sûreté

Règles
- séparer faisceaux puissance et signaux
- éviter longues lignes non blindées pour fins de course
- pull-up ou pull-down pour éviter entrées flottantes

---

## 6) Caméra et vision

Règles
- montage stable, limiter vibrations
- câble caméra séparé des câbles moteurs
- éviter angles de pliage trop serrés
- protéger la lentille et la nettoyer

---

## 7) Distribution puissance

Structure faisceau recommandée
- tronc fort courant court batterie vers distribution
- branches vers
  - DC-DC
  - drivers moteurs
  - distribution 5 V compute

Règles
- fusible proche batterie
- câbles épais sur segments forts courants
- connecteurs fiables et bien dimensionnés
- polarité clairement marquée

---

## 8) Étiquetage et maintenance

Tout étiqueter
- branches puissance
- câbles Ethernet
- moteurs et drivers
- capteurs

Kit service
- fusibles
- câble Ethernet
- jumpers
- multimètre

---

## 9) Checklist acceptance

- aucun fil libre proche des mécanismes mobiles
- actionnement OK sans perturber Ethernet
- Ethernet stable pendant mouvement moteur
- aucun reset au démarrage moteur
- BMS ne déclenche pas en pics normaux
- tous les nœuds bootent et publient heartbeats

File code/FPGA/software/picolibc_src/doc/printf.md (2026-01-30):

# Printf and Scanf in Picolibc

Embedded systems are often tightly constrained on code space, which
makes it important to be able to only include code and data actually
needed by the application. The format-string based interface to
printf and scanf makes it very difficult to determine which
conversion operations might be needed by the application.

Picolibc handles this by providing multiple printf and scanf
implementations in the library with varying levels of conversion
support. The application developer selects among these at compile and
link time based on knowledge of the requirements of the
application. The selection is done using a compiler command line
definition of a preprocessor symbol which maps the public printf and
scanf names to internal names in the linker.

The function name mapping happens in picolibc.specs file which scans
the compiler command line looking for the preprocessor token and uses
that to add --defsym options when linking. This means the preprocessor
definition must be set on the command line and not in a file.

Using the defsym approach, rather than renaming the functions with the
C preprocessor has a couple of benefits:

 * Printf uses within picolibc (which are all integer-only) now share
   whichever printf the application needs, avoiding including both
   integer-only and float versions

 * Printf optimizations in the compiler which map to puts or fputs now
   work even when using integer-only or float printf functions.

Because the linker gets --defsym flags for both vfprintf and vfscanf,
those functions will always get included in the link process. To avoid
linking them into the application when they aren't otherwise needed,
picolibc.specs includes the --gc-sections linker flag. This causes
those functions to be discarded if they aren't used in the
application.

However, the defsym approach does not work with link-time
optimization. In that case, applications can only use the default
function. For that case, the library needs to allow a different
default version to be selected while compiling the library.

## Printf and Scanf levels in Picolibc

There are three levels of printf support provided by Picolibc that can
be selected when building applications. One of these is the default
used when no symbol definitions are applied; that is selected using
the picolibc built-time option, `-Dformat-default`, which defaults to
`double`, selecting PICOLIBC_DOUBLE_PRINTF_SCANF.

 * PICOLIBC_DOUBLE_PRINTF_SCANF (default when
   `-Dformat-default=double`). This offers full printf functionality,
   including both float and double conversions. The picolibc.specs
   stanza that matches this option maps __d_vfprintf to vfprintf and
   __d_vfscanf to vfscanf. This is equivalent to adding this when
   linking your application:

	cc -Wl,--defsym=vfprintf=__d_vfprintf -Wl,--defsym=vfscanf=__d_vfscanf

   If you're using a linker that supports -alias instead of --defsym,
   you  would use:

	cc -Wl,-alias,___d_vfprintf,_vfprintf -Wl,-alias,___d_vfscanf,_vfscanf

 * PICOLIBC_INTEGER_PRINTF_SCANF (default when
   `-Dformat-default=integer`). This removes support for all float and
   double conversions. The picolibc.specs stanza that matches this
   option maps __i_vfprintf to vfprintf and __i_vfscanf to
   vfscanf. This is equivalent to adding this when linking your
   application:

	cc -Wl,--defsym=vfprintf=__i_vfprintf -Wl,--defsym=vfscanf=__i_vfscanf

   If you're using a linker that supports -alias instead of --defsym,
   you  would use:

	cc -Wl,-alias,___i_vfprintf,_vfprintf -Wl,-alias,___i_vfscanf,_vfscanf

 * PICOLIBC_FLOAT_PRINTF_SCANF (default when
   `-Dformat-default=float`). This provides support for float, but not
   double conversions. When picolibc.specs finds
   -DPICOLIBC_FLOAT_PRINTF_SCANF on the command line during linking,
   it maps __f_vfprintf to vfprintf and __f_vfscanf to vfscanf. This
   is equivalent to adding this when linking your application:

	cc -Wl,--defsym=vfprintf=__f_vfprintf -Wl,--defsym=vfscanf=__f_vfscanf

   If you're using a linker that supports -alias instead of --defsym,
   you  would use:

	cc -Wl,-alias,___f_vfprintf,_vfprintf -Wl,-alias,___f_vfscanf,_vfscanf

PICOLIBC_FLOAT_PRINTF_SCANF requires a special macro for float values:
`printf_float`. To make it easier to switch between that and the default
level, that macro is also correctly defined for the other two levels.

Here's an example program to experiment with these options:

	#include <stdio.h>

	void main(void) {
		printf(" 2⁶¹ = %lld π ≃ %.17g\n", 1ll << 61, printf_float(3.141592653589793));
	}

Now we can build and run it with the double options:

	$ arm-none-eabi-gcc -DPICOLIBC_DOUBLE_PRINTF_SCANF -Os -march=armv7-m --specs=picolibc.specs --oslib=semihost --crt0=hosted -Wl,--defsym=__flash=0 -Wl,--defsym=__flash_size=0x00200000 -Wl,--defsym=__ram=0x20000000 -Wl,--defsym=__ram_size=0x200000 -o printf.elf printf.c
	$ arm-none-eabi-size printf.elf
	   text	   data	    bss	    dec	    hex	filename
           7760	     80	   2056	   9896	   26a8	printf.elf
	$ qemu-system-arm -chardev stdio,id=stdio0 -semihosting-config enable=on,chardev=stdio0 -monitor none -serial none -machine mps2-an385,accel=tcg -kernel printf.elf -nographic
	 2⁶¹ = 2305843009213693952 π ≃ 3.141592653589793

Switching to float-only reduces the size but lets this still work,
although the floating point value has reduced precision:

	$ arm-none-eabi-gcc -DPICOLIBC_FLOAT_PRINTF_SCANF -Os -march=armv7-m --specs=picolibc.specs --oslib=semihost --crt0=hosted -Wl,--defsym=__flash=0 -Wl,--defsym=__flash_size=0x00200000 -Wl,--defsym=__ram=0x20000000 -Wl,--defsym=__ram_size=0x200000 -o printf-float.elf printf.c
	$ arm-none-eabi-size printf-float.elf
	   text	   data	    bss	    dec	    hex	filename
           6232	     80	   2056	   8368	   20b0	printf-float.elf
	$ qemu-system-arm -chardev stdio,id=stdio0 -semihosting-config enable=on,chardev=stdio0 -monitor none -serial none -machine mps2-an385,accel=tcg -kernel printf-float.elf -nographic
	 2⁶¹ = 2305843009213693952 π ≃ 3.1415927

Going to integer-only reduces the size even further, but now it doesn't output
the values correctly:

	$ arm-none-eabi-gcc -DPICOLIBC_INTEGER_PRINTF_SCANF -Os -march=armv7-m --specs=picolibc.specs --oslib=semihost --crt0=hosted -Wl,--defsym=__flash=0 -Wl,--defsym=__flash_size=0x00200000 -Wl,--defsym=__ram=0x20000000 -Wl,--defsym=__ram_size=0x200000 -o printf-int.elf printf.c
	$ arm-none-eabi-size printf-int.elf
	   text	   data	    bss	    dec	    hex	filename
           1856	     80	   2056	   3992	    f98	printf-int.elf
	$ qemu-system-arm -chardev stdio,id=stdio0 -semihosting-config enable=on,chardev=stdio0 -monitor none -serial none -machine mps2-an385,accel=tcg -kernel printf-int.elf -nographic
         2⁶¹ = 0 π ≃ *float*

## Picolibc build options for printf and scanf options 

In addition to the application build-time options, picolibc includes a
number of picolibc build-time options to control the feature set (and
hence the size) of the library:

 * `-Dio-c99-formats=true` This option controls whether support for
   the C99 type-specific format modifiers 'j', 'z' and 't' and the hex
   float format 'a' are included in the library. Support for the C99
   format specifiers like PRId8 is always provided.  This option is
   enabled by default.

 * `-Dio-long-long=true` This option controls whether support for long
   long types is included in the integer-only version of printf and
   scanf. long long support is always included in the full and
   float-only versions of printf and scanf. This option is disabled by
   default.

 * `-Dio-float-exact=true` This option, which is enabled by default,
   controls whether the tinystdio code uses exact algorithms for
   printf and scanf. When enabled, printing at least 9 digits
   (e.g. "%.9g") for 32-bit floats and 17 digits (e.g. "%.17g") for
   64-bit floats ensures that passing the output back to scanf will
   exactly re-create the original value.

 * `-Datomic-ungetc=true` This option, which is enabled by default,
   controls whether getc/ungetc use atomic instruction sequences to
   make them re-entrant. Without this option, multiple threads using
   getc and ungetc may corrupt the state of the input buffer.

For compatibility with newlib printf and scanf functionality, picolibc
can be compiled with the original newlib stdio code. That greatly
increases the code and data sizes of the library, including adding a
requirement for heap support in the run time system. Here are the
picolibc build options for that code:

 * `-Dtinystdio=false` This disables the tinystdio code and uses
   original newlib stdio code.

 * `-Dnewlib-io-pos-args=true` This option add support for C99
   positional arguments (e.g. "%1$"). This option is disabled by default.

 * `-Dnewlib-io-long-double=true` This option add support long double
   parameters. That is limited to systems using 80- and 128- bit long
   doubles, or systems for which long double is the same as
   double. This option is disabled by default

 * `-Dnewlib-stdio64=true` This option changes the newlib stdio code
   to use 64 bit values for file sizes and offsets. It also adds
   64-bit versions of stdio interfaces which are defined with types
   which may be 32-bits (like 'long'). This option is enabled by default.

### Newlib floating point printf

To build the `printf` sample program using the original newlib stdio
code, the first step is to build picolibc with the right options.  The
'nano' printf code doesn't support long-long integer output, so we
can't use that, and we need to enable long-long and floating point
support in the full newlib stdio code:

        $ mkdir build-arm; cd build-arm
        $ ../scripts/do-arm-configure -Dtinystdio=false -Dio-long-long=true -Dnewlib-io-float=true
        $ ninja install

Now we can build the example with the library:

        $ arm-none-eabi-gcc -Os -march=armv7-m --specs=picolibc.specs --oslib=semihost --crt0=hosted -Wl,--defsym=__flash=0 -Wl,--defsym=__flash_size=0x00200000 -Wl,--defsym=__ram=0x20000000 -Wl,--defsym=__ram_size=0x200000 -o printf.elf printf.c
	$ arm-none-eabi-size printf.elf
           text	   data	    bss	    dec	    hex	filename
          16008	    824	   2376	  19208	   4b08	printf.elf
        $ qemu-system-arm -chardev stdio,id=stdio0 -semihosting-config enable=on,chardev=stdio0 -monitor none -serial none -machine mps2-an385,accel=tcg -kernel printf.elf -nographic
         2⁶¹ = 2305843009213693952 π ≃ 3.1415926535897931

This also uses 2332 bytes of space from the heap at runtime. Tinystdio
saves 8088 bytes of text space and a total of 3396 bytes of data
space.

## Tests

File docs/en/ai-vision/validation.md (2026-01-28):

Language: English | [Français](../../fr/ai-vision/validation.md)

# Vision Validation Plan (Field-Oriented)

This document defines a practical validation plan for SysPark’s license plate recognition module. The goal is not to achieve perfect OCR in all conditions, but to ensure the system behaves correctly:
- **high-confidence outputs are reliable enough to automate session matching**,
- **low-confidence outputs never block the lane**,
- **fallback identification remains smooth**,
- performance remains stable over long runtimes.

---

## 1) Validation objectives

### Core objectives
- Verify end-to-end plate event publishing to MQTT.
- Verify confidence thresholds behave as intended.
- Verify session matching benefits at exit (reduced operator interventions).
- Verify the system remains safe and usable when vision fails.

### Secondary objectives
- Characterize performance across lighting and weather conditions.
- Identify camera placement constraints and minimum quality requirements.
- Define regression tests to prevent future degradation.

---

## 2) Test environments (recommended set)

To avoid “lab-only” bias, test in multiple environments:

### A) Controlled indoor / lab
- consistent lighting,
- repeatable distances,
- useful for early debugging.

### B) Realistic outdoor lane
- day and night,
- variable lighting and glare,
- realistic vehicle approach angles.

### C) Stress environment
- moving vehicles with higher speed,
- poor weather (rain/fog) if possible,
- low-light conditions.

---

## 3) Test scenarios (what to run)

### Scenario 1: Static vehicle, ideal conditions
- Vehicle stopped at the expected capture point.
- Goal: verify baseline detection + OCR.

Expected:
- high confidence,
- stable plate across frames.

### Scenario 2: Slow approach, daytime
- Vehicle approaching slowly, slight motion blur.
- Goal: validate multi-frame aggregation.

Expected:
- consistent final plate,
- confidence improves with consensus.

### Scenario 3: Night mode with artificial lighting
- Low light, headlight glare.
- Goal: detect failure modes and ensure thresholds protect the flow.

Expected:
- more medium/low confidence,
- no lane blocking.

### Scenario 4: Occlusion and dirt
- Partially covered plate or dirty plate.
- Goal: ensure system does not “hallucinate” and over-trust.

Expected:
- low confidence or invalid plate,
- fallback triggered.

### Scenario 5: Multiple vehicles / reflections
- Vehicle with reflective surfaces or background patterns.
- Goal: validate detector false positives handling.

Expected:
- best-candidate selection stable,
- low confidence on false positives.

### Scenario 6: Exit session matching
- Real sessions created at entry then matched at exit.
- Goal: measure operational improvement.

Expected:
- high-confidence matches reduce manual selection.

---

## 4) Data collection method (practical)

For each run, collect:
- timestamp,
- lane (entry/exit),
- final plate and confidence,
- validity flag,
- top candidate list (optional),
- time-to-result (latency),
- ground-truth plate label (operator noted).

Important:
- avoid storing full video unless necessary.
- if storing frames for debugging, restrict access and retention.

---

## 5) Metrics (what to measure)

### Accuracy metrics
- **Detection success rate**: % of triggers where a plate region was detected.
- **OCR exact match rate**: % where final plate equals ground truth.
- **High-confidence precision**: when confidence >= HIGH, % correct.
- **Medium-confidence usefulness**: % where the correct plate appears in candidates.

### Calibration metrics
- **Confidence reliability**: high confidence should be rarely wrong.
- **False positive rate**: rate of valid-looking but wrong plates.

### Performance metrics
- **Time-to-result**: trigger → publish event.
- **CPU utilization** (edge device stability, qualitative is acceptable).
- **Memory stability** over long runtime.

---

## 6) Acceptance thresholds (deployment-oriented)

Because conditions vary per site, define acceptance per deployment, but a realistic baseline:

- High-confidence precision: very high (aim for “rarely wrong”).
- Low-confidence results must never block lane flow.
- Typical time-to-result: fast enough to keep driver experience smooth.
- Stable behavior for multi-hour runs (no memory leaks, no crash loops).

If a deployment cannot reach the target:
- adjust camera placement and lighting first,
- then tune thresholds.

---

## 7) Regression checklist (to prevent future breaks)

Whenever the vision module changes (models, camera, parameters), rerun:
- Scenario 1 (baseline),
- Scenario 3 (night/glare),
- Scenario 4 (occlusion),
- Exit session matching scenario (end-to-end).

Additionally verify:
- MQTT payload contract unchanged,
- thresholds unchanged or documented,
- fallback behavior still works.

---

## 8) Operational decision rules (how to use results)

- If high-confidence precision is not acceptable, raise HIGH threshold.
- If the system is too conservative and reduces automation too much, lower HIGH slightly but only if precision remains good.
- If false positives occur, tighten format validation and candidate filtering.
- If time-to-result is too high, reduce frame burst size or optimize the pipeline.

---

## 9) Final integration “pass” criteria

Vision is considered production-usable in SysPark when:
- it publishes reliable structured events,
- high-confidence results are trustworthy enough to automate matching,
- lane flows remain smooth under low-confidence conditions,
- the system does not depend on vision to remain safe.

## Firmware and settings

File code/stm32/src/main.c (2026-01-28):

/*
 * STM32F746G-DISCO — Main Controller
 * Gestion double rôle : BORNE D'ENTRÉE / BORNE DE SORTIE
 */

#include <zephyr/sys/reboot.h>
#include <zephyr/logging/log.h>
LOG_MODULE_REGISTER(main, LOG_LEVEL_INF);

#include <zephyr/device.h>
#include <zephyr/devicetree.h>
#include <zephyr/drivers/display.h>
#include <zephyr/kernel.h>
#include <lvgl.h>
#include <zephyr/fs/fs.h>
#include <zephyr/storage/disk_access.h>
#include <ff.h>
#include <strings.h>
#include <string.h>
#include <stdio.h>
#include <ctype.h>
#include <errno.h>

/* Configuration des rôles */
#include "role_config.h"

/* Déclaration compatible LVGL v9 */
LV_IMAGE_DECLARE(QR_code);

/* -------------------- Config / Constantes -------------------- */
#define UID_STR_LEN         16
#define UID_HANDLER_STACK   4096
#define UID_HANDLER_PRIO    3
#define DEFAULT_PIN         "1234"
#define DEFAULT_EXIT_PIN    "0000"
#define SCREENSAVER_TIMEOUT 3000  /* 3000 * 10ms = 30 secondes */

/* -------------------- Globals -------------------- */
K_MUTEX_DEFINE(sd_lock);

K_SEM_DEFINE(payment_success_sem, 0, 1);

static char current_pin_code[10] = DEFAULT_PIN;
static char current_exit_pin_code[10] = DEFAULT_EXIT_PIN;
static int inactivity_counter = 0;
static bool is_dimmed = false;

/* UI Objects */
static lv_obj_t *home_scr, *pin_ta, *pin_kb, *label_status, *banner_cont = NULL, *banner_label = NULL;
static lv_obj_t *settings_scr, *new_pin_ta, *new_pin_kb = NULL, *label_admin_status;
static lv_obj_t *qr_popup = NULL; 
static lv_obj_t *dimmer_layer = NULL; /* Le voile noir */
static lv_timer_t *qr_autoclose_timer = NULL; 

/* Variable globale pour le sélecteur Admin */
static lv_obj_t *pin_type_roller = NULL;

/* Variables d'État */
static bool parking_is_full = false; /* false = places libres */
static bool admin_active = false;
static int64_t admin_expire_time = 0;
static bool admin_request_pending = false;
static bool add_badge_mode = false;
static lv_timer_t *admin_wait_timer = NULL;

/* Queue de message pour le paiement / infos serveur */
struct payment_info {
    char plate[16];
    char price[10];
    char cause[64];
};
K_MSGQ_DEFINE(payment_msgq, sizeof(struct payment_info), 4, 4);

/* Externs */
extern void mqtt_thread(void *, void *, void *);
extern void mqtt_send_uid(const char *uid);

/* Ces threads ne sont lancés qu'en mode ENTREE */
#ifdef BOARD_ROLE_ENTRY
    extern void ascenseur_thread(void *, void *, void *);
    K_THREAD_DEFINE(ascenseur_tid, 4096, ascenseur_thread, NULL, NULL, NULL, 8, 0, 0);
#endif

extern void publish_acl_list(void);

#define MQTT_THREAD_STACK_SIZE 4096
#define MQTT_THREAD_PRIORITY   1
K_THREAD_STACK_DEFINE(mqtt_stack_area, MQTT_THREAD_STACK_SIZE);
static struct k_thread mqtt_thread_data;

K_MSGQ_DEFINE(uid_msgq, UID_STR_LEN, 4, 4);

static const char * btnm_map[] = { "1", "2", "3", "\n", "4", "5", "6", "\n", "7", "8", "9", "\n", LV_SYMBOL_BACKSPACE, "0", LV_SYMBOL_OK, "" };
static const lv_btnmatrix_ctrl_t btnm_ctrl[] = { 1, 1, 1, 1, 1, 1, 1, 1, 1, 1, 1, 1 };

/* SD Card Utils */
static FATFS fat_fs;
static struct fs_mount_t fs_mnt = { .type = FS_FATFS, .mnt_point = "/SD:", .fs_data = &fat_fs };
static int sd_ready = 0;

static void load_pin_from_sd(void) {
    if (!sd_ready) return;
    struct fs_file_t f; 

    k_mutex_lock(&sd_lock, K_FOREVER);

    /* 1. Chargement PIN ENTRÉE */
    fs_file_t_init(&f);
    if (fs_open(&f, "/SD:/pin.txt", FS_O_READ) >= 0) {
        char buf[16]; ssize_t n = fs_read(&f, buf, sizeof(buf) - 1);
        if (n > 0) {
            buf[n] = '\0'; char *p = strpbrk(buf, "\r\n"); if (p) *p = '\0';
            if (strlen(buf) > 0) strncpy(current_pin_code, buf, sizeof(current_pin_code)-1);
        }
        fs_close(&f);
    } else {
        if (fs_open(&f, "/SD:/pin.txt", FS_O_CREATE | FS_O_WRITE) >= 0) {
            fs_write(&f, DEFAULT_PIN, strlen(DEFAULT_PIN)); fs_close(&f);
        }
    }

    /* 2. Chargement PIN SORTIE */
    fs_file_t_init(&f);
    if (fs_open(&f, "/SD:/exit_pin.txt", FS_O_READ) >= 0) {
        char buf[16]; ssize_t n = fs_read(&f, buf, sizeof(buf) - 1);
        if (n > 0) {
            buf[n] = '\0'; char *p = strpbrk(buf, "\r\n"); if (p) *p = '\0';
            if (strlen(buf) > 0) strncpy(current_exit_pin_code, buf, sizeof(current_exit_pin_code)-1);
        }
        fs_close(&f);
    } else {
        if (fs_open(&f, "/SD:/exit_pin.txt", FS_O_CREATE | FS_O_WRITE) >= 0) {
            fs_write(&f, DEFAULT_EXIT_PIN, strlen(DEFAULT_EXIT_PIN)); fs_close(&f);
        }
    }

    k_mutex_unlock(&sd_lock);
    LOG_INF("🔐 PINS Chargés: In='%s', Out='%s'", current_pin_code, current_exit_pin_code);
}

void save_pin_to_sd(const char *new_pin) {
    if (!new_pin || strlen(new_pin) == 0) return;
    k_mutex_lock(&sd_lock, K_FOREVER);
    
    memset(current_pin_code, 0, sizeof(current_pin_code));
    strncpy(current_pin_code, new_pin, sizeof(current_pin_code)-1);
    LOG_INF("🔑 PIN Entrée MAJ en RAM: %s", current_pin_code);

    if (sd_ready) {
        struct fs_file_t f; fs_file_t_init(&f);
        if (fs_open(&f, "/SD:/pin.txt", FS_O_CREATE | FS_O_WRITE | FS_O_TRUNC) >= 0) {
            fs_write(&f, new_pin, strlen(new_pin)); fs_close(&f);
        }
    }
    k_mutex_unlock(&sd_lock);
}

void save_exit_pin_to_sd(const char *new_pin) {
    if (!new_pin || strlen(new_pin) == 0) return;
    k_mutex_lock(&sd_lock, K_FOREVER);
    
    memset(current_exit_pin_code, 0, sizeof(current_exit_pin_code));
    strncpy(current_exit_pin_code, new_pin, sizeof(current_exit_pin_code)-1);
    LOG_INF("🔑 PIN Sortie MAJ en RAM: %s", current_exit_pin_code);

    if (sd_ready) {
        struct fs_file_t f; fs_file_t_init(&f);
        if (fs_open(&f, "/SD:/exit_pin.txt", FS_O_CREATE | FS_O_WRITE | FS_O_TRUNC) >= 0) {
            fs_write(&f, new_pin, strlen(new_pin)); fs_close(&f);
        }
    }
    k_mutex_unlock(&sd_lock);
}

static void uid_normalize8(const char *in, char *out, size_t out_sz) {
    size_t j = 0;
    for (size_t i = 0; in[i] != '\0' && j < 8 && j < out_sz - 1; i++) {
        char c = in[i];
        if ((c >= '0' && c <= '9') || (c >= 'A' && c <= 'F') || (c >= 'a' && c <= 'f')) {
            if (c >= 'a' && c <= 'f') {
                c -= 32; 
            }
            out[j++] = c;
        }
    }
    out[j] = '\0';
}

static int append_user_badge_local(const char *uid_hex) {
    if (!sd_ready) return -1;
    char uid8[9]; uid_normalize8(uid_hex, uid8, sizeof(uid8));
    k_mutex_lock(&sd_lock, K_FOREVER);
    struct fs_file_t f; fs_file_t_init(&f);
    if (fs_open(&f, "/SD:/users.txt", FS_O_CREATE | FS_O_WRITE | FS_O_APPEND) < 0) { k_mutex_unlock(&sd_lock); return -1; }
    char line[64]; snprintf(line, sizeof(line), "badge:%s\n", uid8);
    fs_write(&f, line, strlen(line)); fs_close(&f);
    k_mutex_unlock(&sd_lock);
    return 0;
}

static void init_sd_card(void) {
    int rc = fs_mount(&fs_mnt);
    if (rc != 0 && rc != -EBUSY) { sd_ready = 0; return; }
    struct fs_file_t f; fs_file_t_init(&f);
    rc = fs_open(&f, "/SD:/users.txt", FS_O_READ);
    if (rc < 0 && rc != -ENOENT) { fs_close(&f); sd_ready = 0; return; }
    if (rc >= 0) fs_close(&f);
    sd_ready = 1; load_pin_from_sd();
}

static bool check_uid_in_file(const char *uid_hex) {
    if (!sd_ready) return false;
    struct fs_file_t f; fs_file_t_init(&f);
    k_mutex_lock(&sd_lock, K_FOREVER);
    if (fs_open(&f, "/SD:/users.txt", FS_O_READ) < 0) { k_mutex_unlock(&sd_lock); return false; }
    char line[128]; int pos = 0; char c; bool ok = false;
    char uid8[9], target8[9]; uid_normalize8(uid_hex, target8, sizeof(target8));
    while (fs_read(&f, &c, 1) == 1) {
        if (c == '\n' || pos >= (int)sizeof(line) - 1) {
            line[pos] = '\0'; pos = 0;
            if (strncasecmp(line, "badge:", 6) == 0) {
                uid_normalize8(line + 6, uid8, sizeof(uid8));
                if (strcmp(uid8, target8) == 0) { ok = true; break; }
            }
        } else line[pos++] = c;
    }
    fs_close(&f); k_mutex_unlock(&sd_lock); return ok;
}

static bool is_admin(const char *uid_hex) {
    char uid8[9]; uid_normalize8(uid_hex, uid8, sizeof(uid8));
    return (strcmp(uid8, "BBC7CD05") == 0);
}

/* Fonction appelée par MQTT Thread pour mettre à jour l'état COMPLET/LIBRE */
void update_parking_status(const char *text) {
    if (strstr(text, "COMPLET") != NULL) {
        parking_is_full = true;
    } else {
        parking_is_full = false;
    }
    
    if (label_status) {
        if (parking_is_full) {
            lv_label_set_text(label_status, "PARKING COMPLET");
            lv_obj_set_style_text_color(label_status, lv_color_hex(0xFF0000), 0);
        } else {
            #ifdef BOARD_ROLE_ENTRY
                lv_label_set_text(label_status, "Veuillez badger");
            #else
                lv_label_set_text(label_status, "Bonne route !");
            #endif
            lv_obj_set_style_text_color(label_status, lv_color_white(), 0);
        }
    }
}

/* UI Callbacks */
static void reset_home_timer_cb(lv_timer_t *t) {
    if (lv_scr_act() == home_scr) { 
        if (parking_is_full) {
            lv_label_set_text(label_status, "PARKING COMPLET");
            lv_obj_set_style_text_color(label_status, lv_color_hex(0xFF0000), 0); // ROUGE
        } else {
            #ifdef BOARD_ROLE_ENTRY
                lv_label_set_text(label_status, "Veuillez badger ou saisir le code");
            #else
                lv_label_set_text(label_status, "Saisissez votre code de sortie");
            #endif
            lv_obj_set_style_text_color(label_status, lv_color_white(), 0); // BLANC
        }
        
        lv_textarea_set_text(pin_ta, ""); 
    }
    lv_timer_del(t);
}

static void hide_banner_cb(lv_timer_t *t) { if (banner_cont) lv_obj_add_flag(banner_cont, LV_OBJ_FLAG_HIDDEN); lv_timer_del(t); }

static void show_banner(const char* text, uint32_t color) {
    inactivity_counter = 0;
    if (is_dimmed && dimmer_layer) {
        lv_obj_add_flag(dimmer_layer, LV_OBJ_FLAG_HIDDEN);
        is_dimmed = false;
    }

    if (!banner_cont) return;
    
    lv_label_set_text(banner_label, text); 
    lv_obj_set_style_bg_color(banner_cont, lv_color_hex(color), 0);
    
    lv_obj_clear_flag(banner_cont, LV_OBJ_FLAG_HIDDEN); 
    lv_obj_move_foreground(banner_cont);
    
    lv_timer_t *t = lv_timer_create(hide_banner_cb, 2000, NULL); 
    lv_timer_set_repeat_count(t, 1);
}

static void show_success_banner(void) { show_banner("OUVERTURE\nAUTORISEE", 0x28a745); }
static void show_denied_banner(void)  { show_banner("ACCES REFUSE", 0xdc3545); }

static void return_to_home(void) {
    admin_active = false; admin_request_pending = false; add_badge_mode = false;
    if (admin_wait_timer) { lv_timer_del(admin_wait_timer); admin_wait_timer = NULL; }
    if (lv_scr_act() != home_scr) lv_scr_load_anim(home_scr, LV_SCR_LOAD_ANIM_MOVE_RIGHT, 200, 0, false);
    lv_textarea_set_text(pin_ta, ""); 
    
    // Remise à zéro du label selon l'état
    lv_timer_t *t = lv_timer_create(reset_home_timer_cb, 100, NULL); 
    lv_timer_set_repeat_count(t, 1);
}

/* Gestion du clavier avec Distinction des Rôles */
static void pin_kb_event_cb(lv_event_t *e) {
    if (lv_event_get_code(e) == LV_EVENT_READY) { 
        const char *txt = lv_textarea_get_text(pin_ta);

        /* ============================
         * LOGIQUE POUR BORNE D'ENTRÉE
         * ============================ */
        #ifdef BOARD_ROLE_ENTRY
            if (strcmp(txt, current_pin_code) == 0) {
                /* 🛑 PROTECTION : On vérifie si c'est COMPLET */
                if (parking_is_full) {
                    show_denied_banner();
                    lv_label_set_text(label_status, "PARKING COMPLET !");
                    lv_obj_set_style_text_color(label_status, lv_color_hex(0xFF0000), 0);
                } else {
                    show_success_banner(); 
                    mqtt_send_uid("PIN_IN"); 
                    lv_label_set_text(label_status, "Code Entree OK");
                }
            } else {
                show_denied_banner(); 
                lv_label_set_text(label_status, "Code incorrect !");
            }
        
        /* ============================
         * LOGIQUE POUR BORNE DE SORTIE
         * ============================ */
        #else 
            if (strcmp(txt, current_exit_pin_code) == 0) {
                /* Sortie toujours autorisée même si complet */
                show_success_banner(); 
                mqtt_send_uid("PIN_OUT"); 
                lv_label_set_text(label_status, "Code Sortie OK");
            }
            else {
                show_denied_banner(); 
                lv_label_set_text(label_status, "Code incorrect !");
            }
        #endif

        lv_timer_t *t = lv_timer_create(reset_home_timer_cb, 3000, NULL); lv_timer_set_repeat_count(t, 1);
        lv_textarea_set_text(pin_ta, "");
    }
}

static void kb_visibility_cb(lv_event_t *e) {
    if (!new_pin_kb) return;
    lv_event_code_t code = lv_event_get_code(e);
    if (code == LV_EVENT_CLICKED || code == LV_EVENT_FOCUSED) { 
        lv_keyboard_set_textarea(new_pin_kb, new_pin_ta); lv_obj_clear_flag(new_pin_kb, LV_OBJ_FLAG_HIDDEN); 
    }
    else if (code == LV_EVENT_READY || code == LV_EVENT_DEFOCUSED) { lv_obj_add_flag(new_pin_kb, LV_OBJ_FLAG_HIDDEN); }
}

static void settings_btn_cb(lv_event_t *e) {
    if (admin_active && k_uptime_get() < admin_expire_time) { lv_scr_load_anim(settings_scr, LV_SCR_LOAD_ANIM_MOVE_LEFT, 200, 0, false); return; }
    admin_request_pending = true; lv_label_set_text(label_status, "BADGEZ ADMIN SVP...");
    if (admin_wait_timer) lv_timer_del(admin_wait_timer);
    admin_wait_timer = lv_timer_create((lv_timer_cb_t)return_to_home, 5000, NULL); lv_timer_set_repeat_count(admin_wait_timer, 1);
}

/* Callback de sauvegarde AVEC choix Entrée/Sortie */
static void save_new_pin_cb(lv_event_t *e) {
    const char *txt = lv_textarea_get_text(new_pin_ta);
    if (strlen(txt) >= 4) {
        /* On regarde la roulette */
        uint16_t selected = lv_roller_get_selected(pin_type_roller);
        
        if (selected == 0) {
            save_pin_to_sd(txt);
            lv_label_set_text(label_admin_status, "Code ENTREE MAJ !");
        } else {
            save_exit_pin_to_sd(txt);
            lv_label_set_text(label_admin_status, "Code SORTIE MAJ !");
        }
        
        lv_textarea_set_text(new_pin_ta, ""); 
        if(new_pin_kb) lv_obj_add_flag(new_pin_kb, LV_OBJ_FLAG_HIDDEN); 
    }
}

static void add_badge_wait_cb(lv_event_t *e) {
    add_badge_mode = true; lv_label_set_text(label_admin_status, "BADGEZ LE NOUVEAU...");
    admin_expire_time = k_uptime_get() + 20000; 
}

/* --- LOGIQUE QR CODE --- */
static void close_qr_cb(lv_event_t *e) {
    if (qr_popup) lv_obj_add_flag(qr_popup, LV_OBJ_FLAG_HIDDEN);
    if (qr_autoclose_timer) {
        lv_timer_del(qr_autoclose_timer);
        qr_autoclose_timer = NULL;
    }
}

static lv_obj_t *lbl_qr_plate = NULL;
static lv_obj_t *lbl_qr_price = NULL;
static lv_obj_t *lbl_qr_warning = NULL;
static lv_obj_t *lbl_qr_title = NULL; 
static lv_obj_t *img_qr_obj = NULL; 

static void qr_autoclose_cb(lv_timer_t *t) {
    if (qr_popup) lv_obj_add_flag(qr_popup, LV_OBJ_FLAG_HIDDEN);
    qr_autoclose_timer = NULL; 
}
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
int main(void) {
    k_msleep(1000);
    const struct device *display_dev = DEVICE_DT_GET(DT_CHOSEN(zephyr_display));
    if (!device_is_ready(display_dev)) return 0;
    
    init_sd_card();
    
    /* Le MQTT tourne sur les deux rôles */
    k_thread_create(&mqtt_thread_data, mqtt_stack_area, K_THREAD_STACK_SIZEOF(mqtt_stack_area), mqtt_thread, NULL, NULL, NULL, MQTT_THREAD_PRIORITY, 0, K_NO_WAIT);
    
    build_home_screen(); 
    build_settings_screen();
    create_dimmer_layer(); 
    
    lv_scr_load(home_scr); 
    display_blanking_off(display_dev);
    
    struct payment_info pay_info;
    
    while (1) { 
        lv_timer_handler(); 
        
        lv_indev_t * indev = lv_indev_get_act();

        if (k_msgq_get(&payment_msgq, &pay_info, K_NO_WAIT) == 0) {
            
            /* GESTION DOUBLE RÔLE DES MESSAGES PAIEMENT */
            
            if (strcmp(pay_info.price, "STOP") == 0) {
                // CAS 1 : "STOP" (Parking Complet) -> Seulement pertinent pour l'ENTRÉE
                #ifdef BOARD_ROLE_ENTRY
                    show_denied_banner(); 
                    char status_msg[64];
                    snprintf(status_msg, sizeof(status_msg), "COMPLET (%s)", pay_info.plate);
                    lv_label_set_text(label_status, status_msg);
                    lv_obj_set_style_text_color(label_status, lv_color_hex(0xFF0000), 0);
                    
                    lv_timer_t *t = lv_timer_create(reset_home_timer_cb, 3000, NULL); 
                    lv_timer_set_repeat_count(t, 1);
                #endif
            } else {
                // CAS 2 : Vrai Prix -> Seulement pertinent pour la SORTIE (QR Code)
                #ifdef BOARD_ROLE_EXIT
                    open_qr_popup(pay_info.plate, pay_info.price, pay_info.cause);
                #endif
            }
        }

	    if (k_sem_take(&payment_success_sem, K_NO_WAIT) == 0) {
            /* Succès Paiement : Utile pour fermer le QR Code sur la sortie */
            LOG_INF("💰 Succès paiement reçu -> Fermeture Popup");
            
            if (qr_popup) {
                lv_obj_add_flag(qr_popup, LV_OBJ_FLAG_HIDDEN);
            }

	        if (qr_autoclose_timer) {
                lv_timer_del(qr_autoclose_timer);
                qr_autoclose_timer = NULL;
            }

            /* Feedback visuel */
            show_success_banner(); 
            
            /* Réveil écran */
            inactivity_counter = 0;
            if (is_dimmed && dimmer_layer) { 
                lv_obj_add_flag(dimmer_layer, LV_OBJ_FLAG_HIDDEN); 
                is_dimmed = false; 
            }
        }

        /* Screensaver Logic */
        if (indev && lv_indev_get_state(indev) == LV_INDEV_STATE_PRESSED) {
            inactivity_counter = 0;
            if (is_dimmed) { is_dimmed = false; if (dimmer_layer) lv_obj_add_flag(dimmer_layer, LV_OBJ_FLAG_HIDDEN); }
        } else {
            inactivity_counter++;
            if (inactivity_counter > SCREENSAVER_TIMEOUT && !is_dimmed) {
                if (dimmer_layer) { lv_obj_clear_flag(dimmer_layer, LV_OBJ_FLAG_HIDDEN); lv_obj_move_foreground(dimmer_layer); }
                is_dimmed = true;
            }
        }
        k_msleep(10); 
    }
}

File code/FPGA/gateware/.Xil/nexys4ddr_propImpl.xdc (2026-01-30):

set_property SRC_FILE_INFO {cfile:/home/karim/fpga/linux-on-litex-vexriscv/build/nexys4ddr/gateware/nexys4ddr.xdc rfile:../nexys4ddr.xdc id:1 order:EARLY} [current_design]
set_property src_info {type:XDC file:1 line:5 export:INPUT save:INPUT read:READ} [current_design]
set_property LOC C12 [get_ports {cpu_reset}]
set_property src_info {type:XDC file:1 line:9 export:INPUT save:INPUT read:READ} [current_design]
set_property LOC E3 [get_ports {clk100}]
set_property src_info {type:XDC file:1 line:13 export:INPUT save:INPUT read:READ} [current_design]
set_property LOC D4 [get_ports {serial_tx}]
set_property src_info {type:XDC file:1 line:17 export:INPUT save:INPUT read:READ} [current_design]
set_property LOC C4 [get_ports {serial_rx}]
set_property src_info {type:XDC file:1 line:21 export:INPUT save:INPUT read:READ} [current_design]
set_property LOC M4 [get_ports {ddram_a[0]}]
set_property src_info {type:XDC file:1 line:26 export:INPUT save:INPUT read:READ} [current_design]
set_property LOC P4 [get_ports {ddram_a[1]}]
set_property src_info {type:XDC file:1 line:31 export:INPUT save:INPUT read:READ} [current_design]
set_property LOC M6 [get_ports {ddram_a[2]}]
set_property src_info {type:XDC file:1 line:36 export:INPUT save:INPUT read:READ} [current_design]
set_property LOC T1 [get_ports {ddram_a[3]}]
set_property src_info {type:XDC file:1 line:41 export:INPUT save:INPUT read:READ} [current_design]
set_property LOC L3 [get_ports {ddram_a[4]}]
set_property src_info {type:XDC file:1 line:46 export:INPUT save:INPUT read:READ} [current_design]
set_property LOC P5 [get_ports {ddram_a[5]}]
set_property src_info {type:XDC file:1 line:51 export:INPUT save:INPUT read:READ} [current_design]
set_property LOC M2 [get_ports {ddram_a[6]}]
set_property src_info {type:XDC file:1 line:56 export:INPUT save:INPUT read:READ} [current_design]
set_property LOC N1 [get_ports {ddram_a[7]}]
set_property src_info {type:XDC file:1 line:61 export:INPUT save:INPUT read:READ} [current_design]
set_property LOC L4 [get_ports {ddram_a[8]}]
set_property src_info {type:XDC file:1 line:66 export:INPUT save:INPUT read:READ} [current_design]
set_property LOC N5 [get_ports {ddram_a[9]}]
set_property src_info {type:XDC file:1 line:71 export:INPUT save:INPUT read:READ} [current_design]
set_property LOC R2 [get_ports {ddram_a[10]}]
set_property src_info {type:XDC file:1 line:76 export:INPUT save:INPUT read:READ} [current_design]
set_property LOC K5 [get_ports {ddram_a[11]}]
set_property src_info {type:XDC file:1 line:81 export:INPUT save:INPUT read:READ} [current_design]
set_property LOC N6 [get_ports {ddram_a[12]}]
set_property src_info {type:XDC file:1 line:86 export:INPUT save:INPUT read:READ} [current_design]
set_property LOC P2 [get_ports {ddram_ba[0]}]
set_property src_info {type:XDC file:1 line:91 export:INPUT save:INPUT read:READ} [current_design]
set_property LOC P3 [get_ports {ddram_ba[1]}]
set_property src_info {type:XDC file:1 line:96 export:INPUT save:INPUT read:READ} [current_design]
set_property LOC R1 [get_ports {ddram_ba[2]}]
set_property src_info {type:XDC file:1 line:101 export:INPUT save:INPUT read:READ} [current_design]
set_property LOC N4 [get_ports {ddram_ras_n}]
set_property src_info {type:XDC file:1 line:106 export:INPUT save:INPUT read:READ} [current_design]
set_property LOC L1 [get_ports {ddram_cas_n}]
set_property src_info {type:XDC file:1 line:111 export:INPUT save:INPUT read:READ} [current_design]
set_property LOC N2 [get_ports {ddram_we_n}]
set_property src_info {type:XDC file:1 line:116 export:INPUT save:INPUT read:READ} [current_design]
set_property LOC T6 [get_ports {ddram_dm[0]}]
set_property src_info {type:XDC file:1 line:121 export:INPUT save:INPUT read:READ} [current_design]
set_property LOC U1 [get_ports {ddram_dm[1]}]
set_property src_info {type:XDC file:1 line:126 export:INPUT save:INPUT read:READ} [current_design]
set_property LOC R7 [get_ports {ddram_dq[0]}]
set_property src_info {type:XDC file:1 line:132 export:INPUT save:INPUT read:READ} [current_design]
set_property LOC V6 [get_ports {ddram_dq[1]}]
set_property src_info {type:XDC file:1 line:138 export:INPUT save:INPUT read:READ} [current_design]
set_property LOC R8 [get_ports {ddram_dq[2]}]
set_property src_info {type:XDC file:1 line:144 export:INPUT save:INPUT read:READ} [current_design]
set_property LOC U7 [get_ports {ddram_dq[3]}]
set_property src_info {type:XDC file:1 line:150 export:INPUT save:INPUT read:READ} [current_design]
set_property LOC V7 [get_ports {ddram_dq[4]}]
set_property src_info {type:XDC file:1 line:156 export:INPUT save:INPUT read:READ} [current_design]
set_property LOC R6 [get_ports {ddram_dq[5]}]
set_property src_info {type:XDC file:1 line:162 export:INPUT save:INPUT read:READ} [current_design]
set_property LOC U6 [get_ports {ddram_dq[6]}]
set_property src_info {type:XDC file:1 line:168 export:INPUT save:INPUT read:READ} [current_design]
set_property LOC R5 [get_ports {ddram_dq[7]}]
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

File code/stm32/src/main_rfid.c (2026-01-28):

#include <zephyr/kernel.h>
#include <zephyr/device.h>
#include <zephyr/drivers/spi.h>
#include <zephyr/drivers/gpio.h>
#include <zephyr/sys/printk.h>
#include <zephyr/logging/log.h>
#include <string.h>
#include <stdio.h>
#include "role_config.h"

LOG_MODULE_REGISTER(rfid_rc522, LOG_LEVEL_INF);

extern struct k_msgq uid_msgq;
#define UID_STR_LEN 16

#define RFID_STACK_SIZE 2048
#define RFID_PRIORITY   5

/* RST matériel RC522 : Toujours sur PG6 */
#define RC522_RST_NODE   DT_NODELABEL(gpiog)
#define RC522_RST_PIN    6

/* Registres MFRC522 */
#define CommandReg       0x01
#define ComIrqReg        0x04
#define ErrorReg         0x06
#define FIFODataReg      0x09
#define FIFOLevelReg     0x0A
#define ControlReg       0x0C
#define BitFramingReg    0x0D
#define CollReg          0x0E
#define ModeReg          0x11
#define TxControlReg     0x14
#define TxASKReg         0x15
#define RFCfgReg         0x26
#define TModeReg         0x2A
#define TPrescalerReg    0x2B
#define TReloadRegH      0x2C
#define TReloadRegL      0x2D
#define CRCResultRegH    0x21
#define CRCResultRegL    0x22
#define VersionReg       0x37

#define PCD_IDLE         0x00
#define PCD_TRANSCEIVE   0x0C
#define PCD_RESETPHASE   0x0F
#define PCD_CALCCRC      0x03
#define PICC_REQIDL      0x26
#define PICC_ANTICOLL    0x93
#define PICC_SELECT_CL1  0x93
#define PICC_HALT        0x50
#define DivIrqReg        0x05

/* * Récupération de la config SPI depuis le DeviceTree 
 * Cela va automatiquement utiliser le CS défini dans l'overlay (PA15)
 */
static const struct spi_dt_spec spi_rc522 =
    SPI_DT_SPEC_GET(DT_NODELABEL(rc522),
                    SPI_WORD_SET(8) | SPI_TRANSFER_MSB | SPI_OP_MODE_MASTER);

static const struct device *gpio_rst;

/* Helpers SPI */
static inline void rc522_write(uint8_t reg, uint8_t val)
{
    uint8_t tx[2] = { (uint8_t)((reg << 1) & 0x7E), val };
    struct spi_buf b = { .buf = tx, .len = 2 };
    struct spi_buf_set s = { .buffers = &b, .count = 1 };
    spi_write_dt(&spi_rc522, &s);
}

static inline uint8_t rc522_read(uint8_t reg)
{
    uint8_t tx[2] = { (uint8_t)(((reg << 1) & 0x7E) | 0x80), 0x00 };
    uint8_t rx[2];
    struct spi_buf bt = { .buf = tx, .len = 2 };
    struct spi_buf br = { .buf = rx, .len = 2 };
    struct spi_buf_set ts = { .buffers = &bt, .count = 1 };
    struct spi_buf_set rs = { .buffers = &br, .count = 1 };
    spi_transceive_dt(&spi_rc522, &ts, &rs);
    return rx[1];
}
    
static inline void rc522_set_bits(uint8_t reg, uint8_t mask) { rc522_write(reg, rc522_read(reg) | mask); }
static inline void rc522_clear_bits(uint8_t reg, uint8_t mask) { rc522_write(reg, rc522_read(reg) & (uint8_t)~mask); }

static void rc522_antenna_on(void)
{
    uint8_t t = rc522_read(TxControlReg);
    if ((t & 0x03) != 0x03) rc522_write(TxControlReg, t | 0x03);
}

static void rc522_init_full(void)
{
    if (device_is_ready(gpio_rst)) {
        gpio_pin_set(gpio_rst, RC522_RST_PIN, 0); k_msleep(5);
        gpio_pin_set(gpio_rst, RC522_RST_PIN, 1); k_msleep(5);
    }
    rc522_write(CommandReg, PCD_RESETPHASE); k_msleep(5);
    rc522_write(TModeReg, 0x8D);
    rc522_write(TPrescalerReg, 0x3E);
    rc522_write(TReloadRegL, 30);
    rc522_write(TReloadRegH, 0);
    rc522_write(ModeReg, 0x3D);
    rc522_write(TxASKReg, 0x40);
    rc522_write(RFCfgReg, 0x70);
    rc522_antenna_on();
}
 
static void rc522_calc_crc(const uint8_t *data, size_t len, uint8_t *crc2)
{
    rc522_write(CommandReg, PCD_IDLE);
    rc522_write(FIFOLevelReg, 0x80);
    for (size_t i = 0; i < len; ++i) rc522_write(FIFODataReg, data[i]);
    rc522_write(DivIrqReg, 0x04);
    rc522_write(CommandReg, PCD_CALCCRC);
    for (int i = 0; i < 25; ++i) {
        if (rc522_read(DivIrqReg) & 0x04) break;
        k_busy_wait(200);
    }
    crc2[0] = rc522_read(CRCResultRegL);
    crc2[1] = rc522_read(CRCResultRegH);
}

static bool rc522_reqa(uint8_t *atqa)
{
    rc522_write(ComIrqReg, 0x7F); rc522_write(FIFOLevelReg, 0x80);
    rc522_write(BitFramingReg, 0x07); rc522_write(FIFODataReg, PICC_REQIDL);
    rc522_write(CommandReg, PCD_TRANSCEIVE); rc522_set_bits(BitFramingReg, 0x80);
    for (int i=0; i<80; ++i) { if (rc522_read(ComIrqReg) & 0x30) break; k_busy_wait(400); }
    rc522_clear_bits(BitFramingReg, 0x80);
    if ((rc522_read(ErrorReg) & 0x13) || (rc522_read(FIFOLevelReg) < 2)) return false;
    atqa[0] = rc522_read(FIFODataReg); atqa[1] = rc522_read(FIFODataReg);
    return true;
}
    
static bool rc522_anticoll(uint8_t *uid5)
{   
    rc522_write(ComIrqReg, 0x7F); rc522_write(FIFOLevelReg, 0x80); 
    rc522_write(BitFramingReg, 0x00); rc522_write(FIFODataReg, PICC_ANTICOLL); rc522_write(FIFODataReg, 0x20);
    rc522_write(CommandReg, PCD_TRANSCEIVE); rc522_set_bits(BitFramingReg, 0x80);
    for (int i=0; i<80; ++i) { if (rc522_read(ComIrqReg) & 0x30) break; k_busy_wait(400); }
    rc522_clear_bits(BitFramingReg, 0x80);
    if ((rc522_read(ErrorReg) & 0x1B) || (rc522_read(FIFOLevelReg) < 5)) return false;
    for (int i=0; i<5; ++i) uid5[i] = rc522_read(FIFODataReg);
    return true;
}
    
static bool rc522_select_uid5(const uint8_t uid5[5], uint8_t *sak)
{
    uint8_t frame[9] = { PICC_SELECT_CL1, 0x70 };
    for (int i=0; i<5; ++i) frame[2+i] = uid5[i];
    uint8_t crc[2]; rc522_calc_crc(frame, 7, crc);
    frame[7] = crc[0]; frame[8] = crc[1];
    
    rc522_write(CommandReg, PCD_IDLE); rc522_write(ComIrqReg, 0x7F);
    rc522_write(FIFOLevelReg, 0x80); rc522_write(BitFramingReg, 0x00);
    for (int i=0; i<9; ++i) rc522_write(FIFODataReg, frame[i]);
    rc522_write(CommandReg, PCD_TRANSCEIVE); rc522_set_bits(BitFramingReg, 0x80);
    for (int i=0; i<80; ++i) { if (rc522_read(ComIrqReg) & 0x30) break; k_busy_wait(400); }
    rc522_clear_bits(BitFramingReg, 0x80);
    if ((rc522_read(ErrorReg) & 0x13) || (rc522_read(FIFOLevelReg) < 1)) return false;
    *sak = rc522_read(FIFODataReg);
    return true;
}
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

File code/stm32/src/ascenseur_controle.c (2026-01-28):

#include <zephyr/kernel.h>
#include <zephyr/device.h>
#include <zephyr/drivers/spi.h>
#include <zephyr/drivers/gpio.h>
#include <zephyr/logging/log.h>
#include <zephyr/sys/util.h>
#include <stdlib.h>
#include <string.h>
#include "role_config.h"

LOG_MODULE_REGISTER(ascenseur, LOG_LEVEL_INF);

/* =========================================================
 * CONFIGURATION TMC5160
 * ========================================================= */
#define TMC5160_GCONF          0x00
#define TMC5160_GSTAT          0x01
#define TMC5160_IHOLD_IRUN     0x10
#define TMC5160_GLOBAL_SCALER  0x0B
#define TMC5160_CHOPCONF       0x6C

static const struct spi_dt_spec spi_spec =
    SPI_DT_SPEC_GET(DT_NODELABEL(tmc5160),
                    SPI_WORD_SET(8) | SPI_MODE_CPOL | SPI_MODE_CPHA);

static const struct gpio_dt_spec en_spec   = GPIO_DT_SPEC_GET(DT_ALIAS(motor_enable), gpios);
static const struct gpio_dt_spec step_spec = GPIO_DT_SPEC_GET(DT_ALIAS(motor_step), gpios);
static const struct gpio_dt_spec dir_spec  = GPIO_DT_SPEC_GET(DT_ALIAS(motor_dir), gpios);
static const struct gpio_dt_spec limit_sw  = GPIO_DT_SPEC_GET(DT_ALIAS(limit_switch), gpios);

/* =========================================================
 * CONFIGURATION MÉCANIQUE
 * ========================================================= */
#define MICROSTEPS     16
#define STEP_PER_FLOOR (3850 * MICROSTEPS) 

#define ACCEL_STEPS    (200 * MICROSTEPS)
#define DECEL_STEPS    (200 * MICROSTEPS)

#define MIN_DELAY_US   200  
#define MAX_DELAY_US   2000 
#define STOP_DELAY_MS  3000

#define BTN_RDC_PIN    2 
#define BTN_1_PIN      6 
#define BTN_2_PIN      7 

static int  current_floor = 0;
static bool going_up = true;
static int  target_floor = -1;
static bool up_requests[3]   = {false, false, false};
static bool down_requests[3] = {false, false, false};
static bool position_lost = false; /* Pour gérer la perte d'alim pendant mouvement */

static bool is_homing = false;

/* =========================================================
 * FONCTIONS BAS NIVEAU TMC5160
 * ========================================================= */
static int tmc_write(uint8_t addr, uint32_t data)
{
    uint8_t tx[5];
    tx[0] = addr | 0x80;
    tx[1] = (uint8_t)(data >> 24);
    tx[2] = (uint8_t)(data >> 16);
    tx[3] = (uint8_t)(data >> 8);
    tx[4] = (uint8_t)(data);
    struct spi_buf buf = { .buf = tx, .len = sizeof(tx) };
    struct spi_buf_set set = { .buffers = &buf, .count = 1 };
    return spi_write_dt(&spi_spec, &set);
}
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

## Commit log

2026-01-28 Add docs index + EN/FR language switch headers + root README
2026-01-28 Docs: system flows (EN/FR)
2026-01-28 Docs: payments and billing flow (EN/FR)
2026-01-28 Docs: LED banner display messaging (EN/FR)
2026-01-28 Docs: STM32 subsystem overview (EN/FR)
2026-01-28 Docs: STM32 Zephyr threading model (EN/FR)
2026-01-28 Docs: STM32 microSD persistence (EN/FR)
2026-01-28 Docs: STM32 Ethernet networking model (EN/FR)
2026-01-28 Docs: FPGA boot chain (LiteX BIOS, OpenSBI, Linux, DTB, initramfs) (EN/FR)
2026-01-28 Docs: hardware BOM, power+BMS, wiring topology (EN/FR)
2026-01-28 Add wiring topology and harnessing documentation
    This document outlines wiring strategies for various components, including power, signal, and motor driver wiring, along with best practices for layout and maintenance.
2026-01-28 Ajout doc stm32
2026-01-28 ajout support 3D
    [ecran_ascenseur_V3.scad, stm32_suppport_arriere.scad, stm32_suppport_avant.scad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]
2026-01-28 ajout .stl meca
    [ecran_ascenseur_V3.stl, stm32_suppport_arriere.stl, stm32_suppport_avant.stl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]
2026-01-28 Reorganize: move docs assets and add code folders
    [ecran_ascenseur_V3.scad, ecran_ascenseur_V3.stl, stm32_suppport_arriere.scad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]
2026-01-30 Add FPGA gateware and software build outputs (Nexys4DDR)
    [intro-machines.json]
